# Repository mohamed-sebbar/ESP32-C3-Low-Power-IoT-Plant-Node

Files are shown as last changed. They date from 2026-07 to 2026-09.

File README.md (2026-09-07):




[]()
[]()

# ESP32-C3 Low-Power IoT Plant Node Rev 2.0

> Design and implementation of a compact low-power ESP32-C3 hardware platform for smart plant monitoring, environmental sensing and automated irrigation.

---

<p align="center">
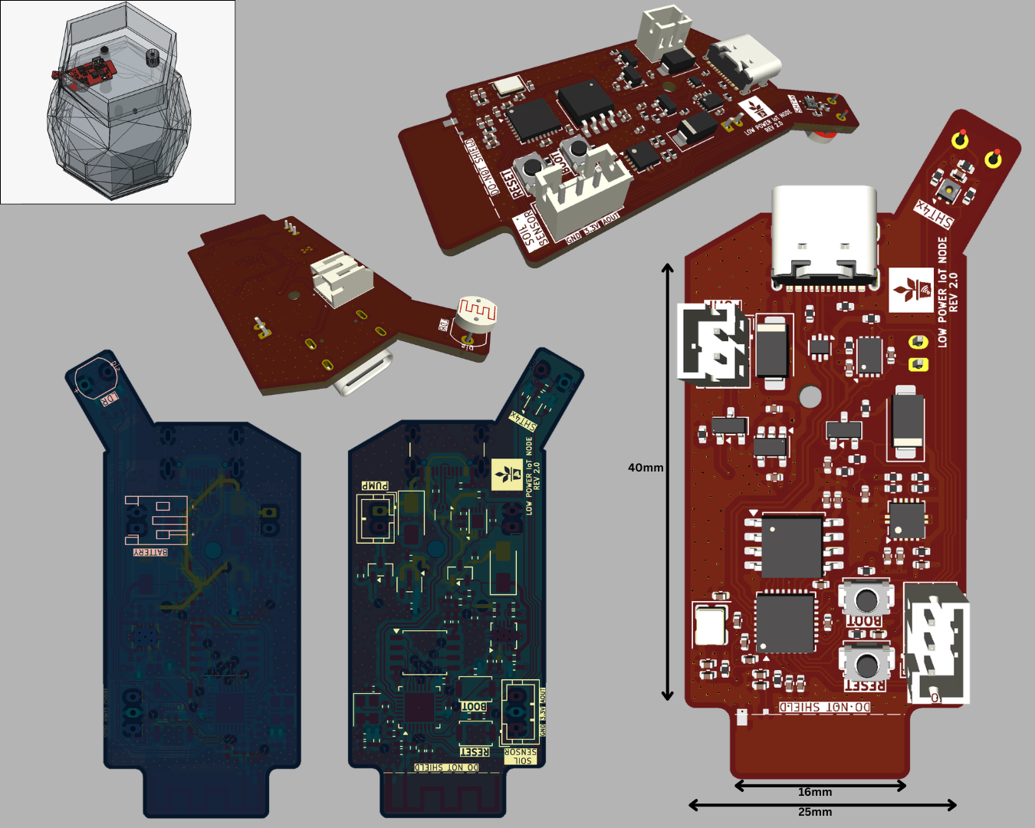
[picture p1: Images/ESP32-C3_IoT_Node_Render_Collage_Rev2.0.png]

</p>

---

## Overview

This repository presents the complete hardware design of a compact ESP32-C3 based IoT plant monitoring node developed as an engineering-focused redesign of a previously demonstrated smart irrigation concept.

Where the original project validated the overall application concept, this work focuses on the complete hardware architecture, RF-aware PCB layout, mixed-signal design, manufacturability, power integrity, and long-term maintainability of a production-oriented embedded platform.

The platform integrates environmental sensing, wireless communication, battery-ready power management and irrigation control within a compact four-layer PCB specifically designed for constrained enclosure geometries.

The goal of this repository is to document the engineering process behind the hardware rather than only presenting a finished PCB.

---

## Contents

- [Overview](#overview)
- [Key Features](#key-features)
- [Hardware Gallery](#hardware-gallery)
- [Repository Structure](#repository-structure)
- [Hardware Architecture](#hardware-architecture)
- [PCB Design Highlights](#pcb-design-highlights)
- [RF Design](#rf-design)
- [Manufacturing](#manufacturing)
- [Documentation](#documentation)
- [Future Work](#future-work)
- [Acknowledgements](#acknowledgements)
- [License](#license)
- [Author](#author)
- [Contact](#contact)

---

## Key Features

- Custom 4-layer PCB
- ESP32-C3 Wi-Fi MCU
- External SPI Flash
- USB-C Programming & Power
- Battery-ready architecture
- Battery charging circuitry
- Reverse polarity protection
- SHT40 Temperature & Humidity Sensor
- Capacitive Soil Moisture Interface
- MOSFET-controlled irrigation pump
- 2.4 GHz PCB antenna based on TI reference design
- RF-aware PCB layout
- Mixed-signal architecture
- Ground stitching
- Manufacturing-ready design

---

## Hardware Gallery

<p align="center">
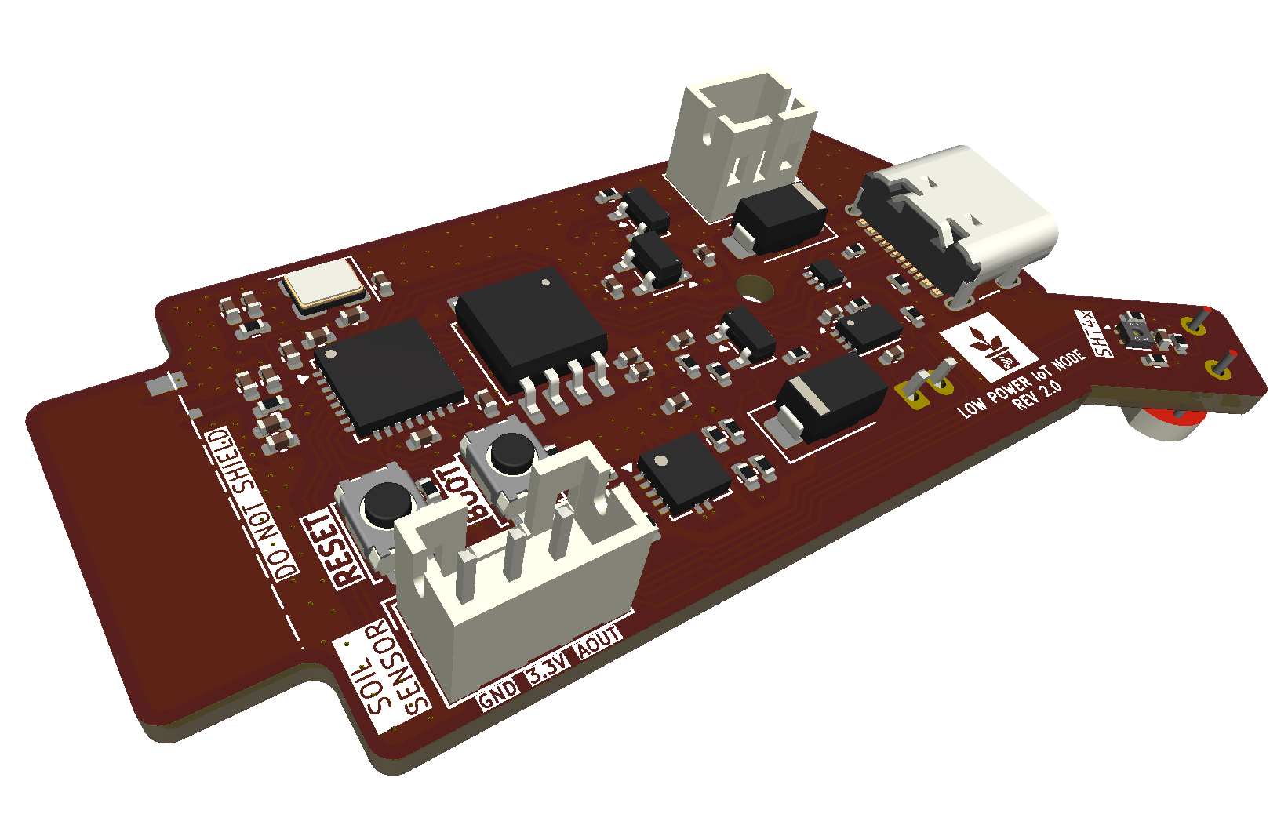
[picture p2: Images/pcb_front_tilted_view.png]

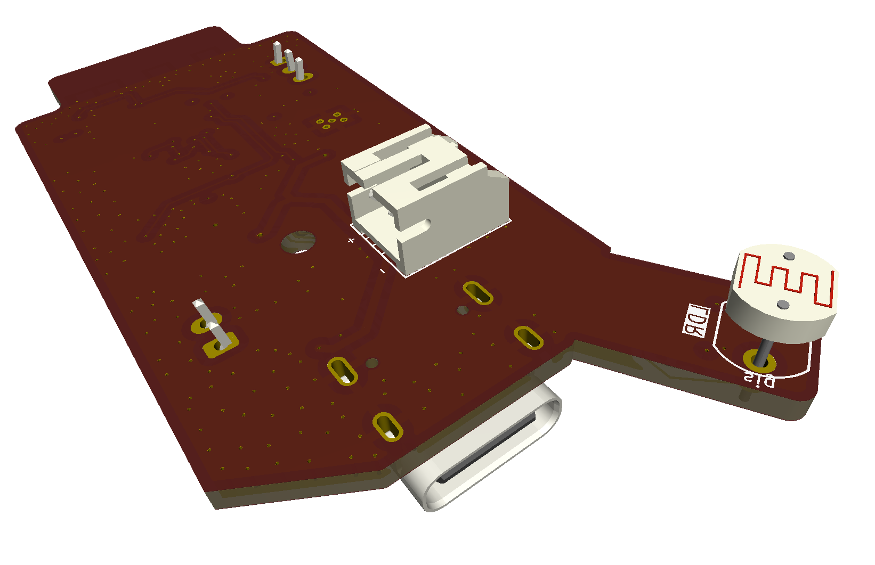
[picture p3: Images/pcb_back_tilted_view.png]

</p>

<p align="center">
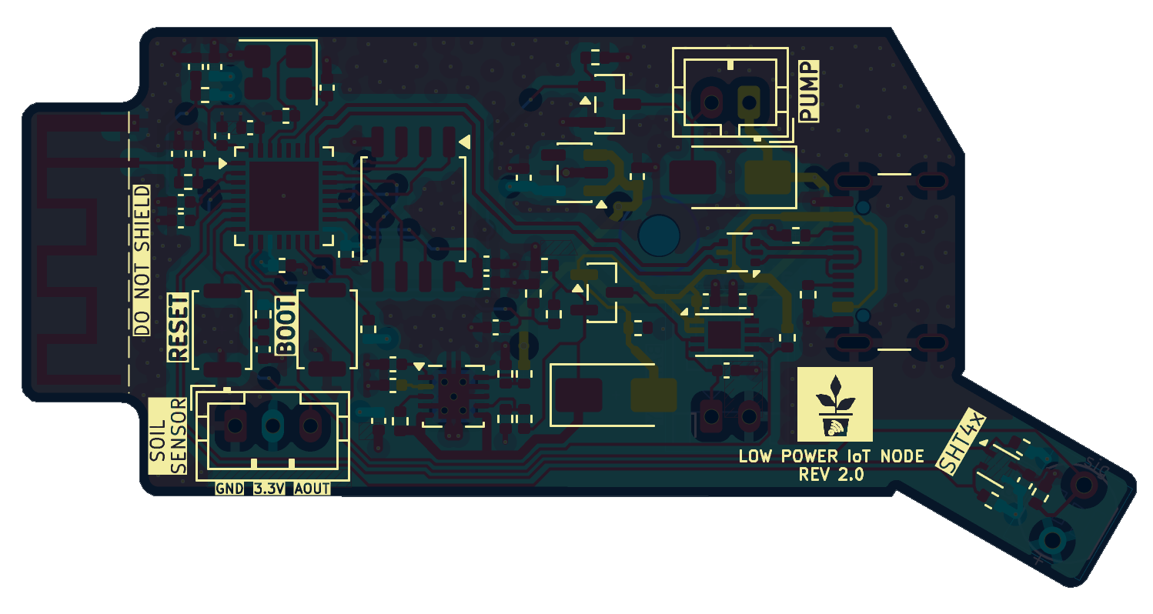
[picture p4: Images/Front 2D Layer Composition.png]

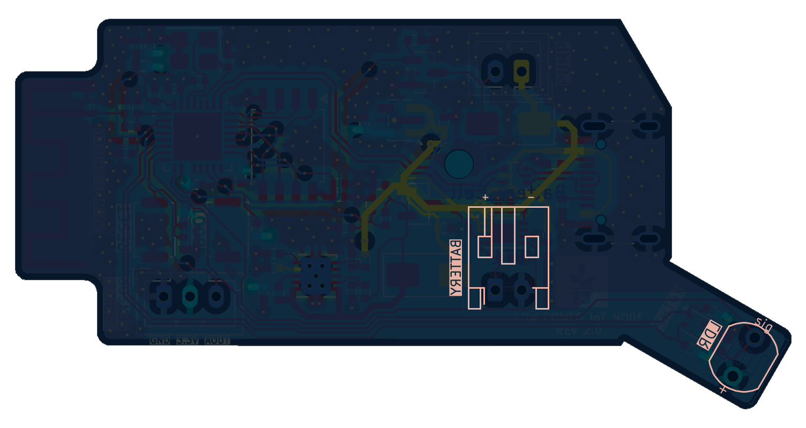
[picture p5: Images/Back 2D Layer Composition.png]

</p>

---

## Repository Structure

```text
ESP32-C3-Low-Power-IoT-Plant-Node

├── Hardware/
│   ├── KiCad Project
│   ├── Production
│   └── Libraries
│
├── Docs/
│   ├── 01_Schematic.pdf
│   └── 02_PCB_Assembly.pdf
│
├── LTspice_Sim
│
├── Images/
│
├── Logos/
│
├── 3D Models/
│
├── LICENSE
└── README.md
```
### Quick Access

- 📁 [Hardware](Hardware/)
- 📁 [Docs](Docs/)
- 📁 [LTspice_Sim](LTspice_Sim/)
- 📁 [Images](Images/)
- 📁 [Logos](Logos/)
- 📁 [3D Models](3D%20Models/)

---

## Hardware Architecture

The platform combines multiple engineering domains within a compact embedded hardware design.

**Processing**

- ESP32-C3
- External SPI Flash

**Environmental Sensing**

- SHT40 Temperature & Humidity
- Capacitive Soil Moisture Sensor

**Irrigation**

- MOSFET Pump Driver
- External Pump Connector

**Connectivity**

- Wi-Fi
- USB-C

**Power**

- USB & Battery powered
- Battery charging supported
- Reverse polarity protection
- Battery voltage monitoring

---

## PCB Design Highlights

The PCB was designed from the ground up with emphasis on engineering practices commonly employed in professional embedded hardware development.

Highlights include

- Four-layer stack-up
- Continuous ground reference planes
- Controlled RF keep-out
- Ground stitching vias
- Short crystal routing
- Careful decoupling placement
- USB differential routing
- Mixed analog/digital partitioning
- Compact constrained mechanical form factor

---

## RF Design

The wireless subsystem employs a PCB antenna derived from Texas Instruments reference **AN043** recommendations.

The antenna region includes

- dedicated RF keep-out
- controlled ground clearance
- dedicated feed routing
- configurable matching network

The initial values of the antenna matching network (L2, C21, C22) were selected based on theoretical calculations and RF design recommendations. Although these values are expected to operate correctly, final impedance matching should be verified after fabrication. For this reason, it is recommended to initially designate L2, C21, and C22 as DNP (Do Not Populate) and populate them only after RF characterization and tuning of the assembled hardware.

Detailed RF design notes will be provided in future documentation.

---

## Manufacturing

The repository includes fabrication outputs required for PCB production.

Included

- Gerber files
- Drill files
- Fabrication outputs

A generic Bill of Materials (BOM) is provided for design reference. Manufacturer-specific part numbers and sourcing information are intentionally omitted, allowing designers the flexibility to select equivalent components based on availability, cost, or project-specific requirements.

---

## Documentation

The repository documentation is being expanded and currently includes

- Schematic
- PCB Assembly
- LTspice power rail stability and transient response plots

Planned additions

- PCB Design Report
- RF Design Notes
- Signal and Power Integrity Discussion
- Design Validation

---

## Future Work

- Firmware adaptation
- Antenna impedance tuning
- Battery validation [Done]
- Power consumption characterization [Done]
- Environmental testing
- Long-term field deployment
- Companion mobile application integration

---

## Acknowledgements

The 3D planter model used in the project renders was created by **Lewis**. Full credit goes to the original author. The original model is available on the **Thingiverse** [Profile](https://www.thingiverse.com/thing:3537287).

The plant icon used on the PCB silkscreen is **"Smart Plant"** by **Anton Handal Saputra**, sourced from the **Noun Project**, and is used under the **Creative Commons Attribution 3.0 (CC BY 3.0)** license: https://thenounproject.com/browse/icons/term/smart-plant/

---

## License

The hardware design files are released under the CERN Open Hardware Licence Version 2 – Permissive (CERN-OHL-P). The accompanying files and written documentation remain © 2026 SEBBAR Mohamed and are provided for reference purposes only.

See [LICENSE](LICENSE) for details.

---

## Author

**Mohamed Sebbar**

Master's Degree in Computer Engineering and Embedded Systems

Faculty of Sciences, Agadir, Morocco

---

## Contact

If you have questions about this project, or would like to discuss the design feel free to:

- Open an [Issue](../../issues).
- Connect with me on [LinkedIn](https://www.linkedin.com/in/mohamedsebbar/).
- Or contact me via [email](mailto:sebbar.mohamed66@gmail.com).

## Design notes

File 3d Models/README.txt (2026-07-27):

Automatic Smart Plant Pot - (DIY, 3D Printed, Arduino, Self Watering, Project) by DIY_Machines on Thingiverse: https://www.thingiverse.com/thing:3537287

Summary:
Sometimes when we go away from home for a few days or are really busy the house plants (unfairly) suffer because they are not watered when they need it. This is my solution.All the electronics, pumps and water reservoir are contained inside the pot to keep it looking smart. Each pot (if you make more than one) can also be set to the needs of different types of plants.It has an Arduino Nano controlling everything and the cost of the components has been kept as low as possible. Below are links to the parts on Amazon.How to build it video: https://youtu.be/T_tpKoNCVYwCORRECTION: 4:05 into the video I incorrectly say to use 20cm wires to connect the water level sensor. The correct length is 35cm.==========List of items used in this project and where to find them (the links are Amazon affiliate links and help support this channel at no cost to you):■ Arduino Nano: https://geni.us/ArduinoNanoV3■ Mini submersible pump: https://geni.us/MiniPump■ 5mm tubing: https://geni.us/5mmTubing■ Transistor: https://geni.us/2npn2222■ Resistors (1k and 4.7k): https://geni.us/Ufa2s■ Wire: https://geni.us/22AWGWire■ 3mm LED: https://geni.us/LEDs■ Water level sensor: https://geni.us/WaterLevelSensor■ Nuts and Bolts: http://geni.us/NutsAndBolts■ Soil moisture sensor: https://geni.us/MoistureSensor■ Half Perma-proto board: https://geni.us/HalfPermaProto■ PLA Filament: https://geni.us/PLAFilament■ Battery powered glue gun: http://geni.us/BoschBatteryGlueGun■ Battery powered soldering iron:  http://bit.ly/SealeySDL6 ==========The code can be downloaded from here: https://github.com/DIY-Machines/SmartPlantV1==========SAY THANKS:Buy me a coffee to say thanks: https://ko-fi.com/diymachinesSupport me on Patreon: https://www.patreon.com/diymachinesSUBSCRIBE:■ https://www.youtube.com/channel/UC3jc4X-kEq-dEDYhQ8QoYnQ?sub_confirmation=1INSTAGRAM: https://www.instagram.com/diy_machines/?hl=enFACEBOOK: https://www.facebook.com/diymachines/Disclaimer:This video is shared for demonstration purposes only.

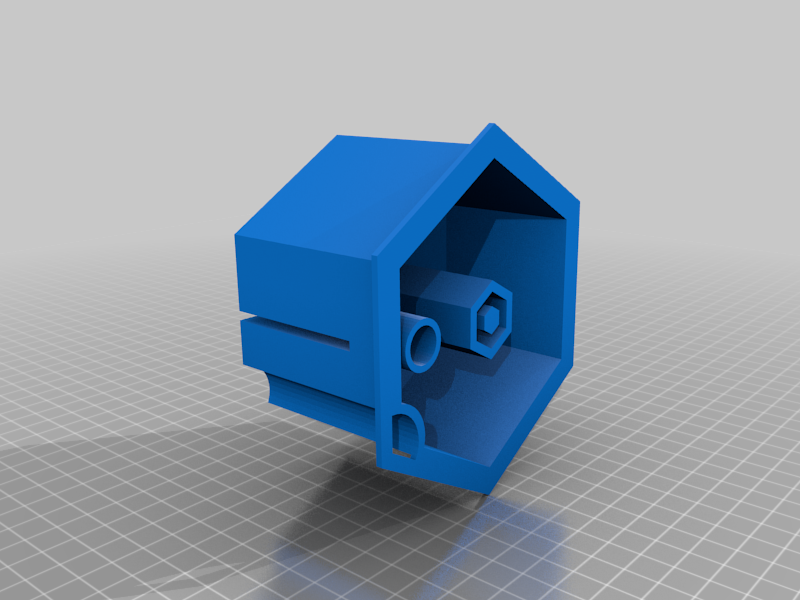
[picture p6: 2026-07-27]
3d Models/images/3d78d03c32c9cba0c1dec2c4151a06b8.png

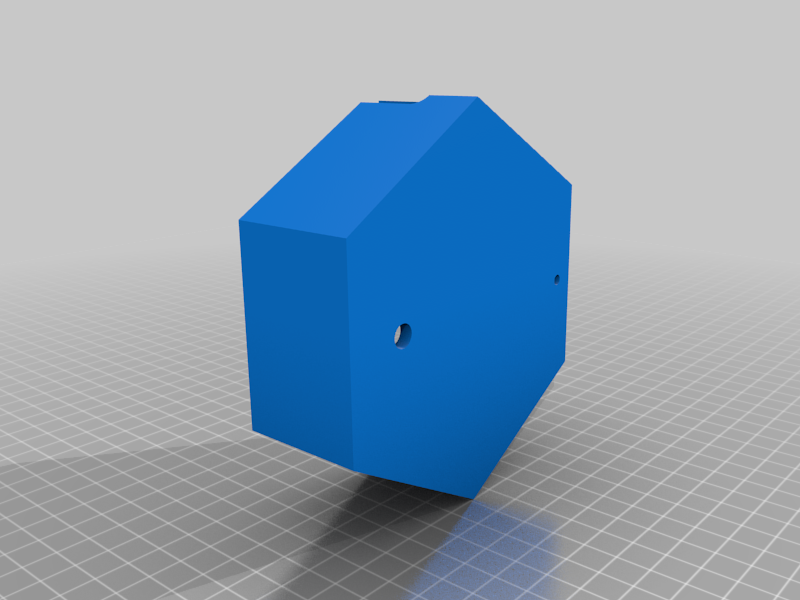
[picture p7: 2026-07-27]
3d Models/images/6778b36fcebb03efd6b67b2f8be7a825.png

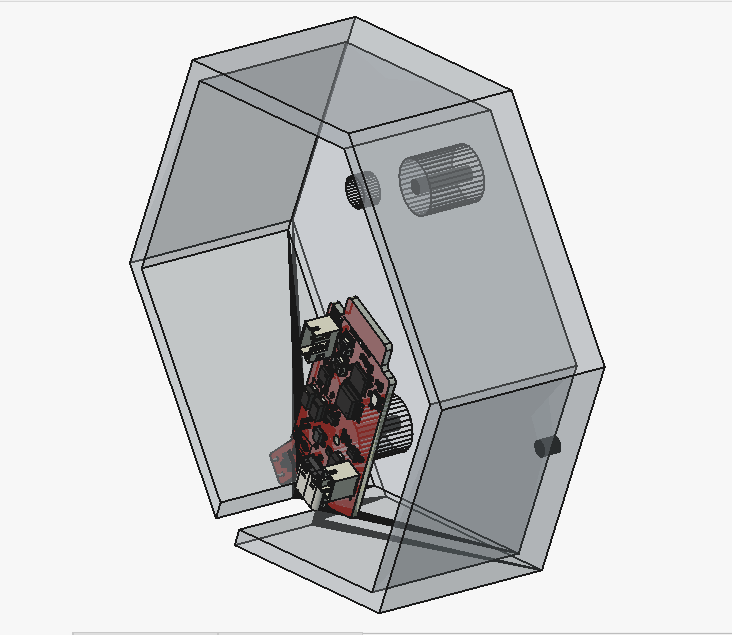
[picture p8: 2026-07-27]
Images/product_tilted_view_2.png

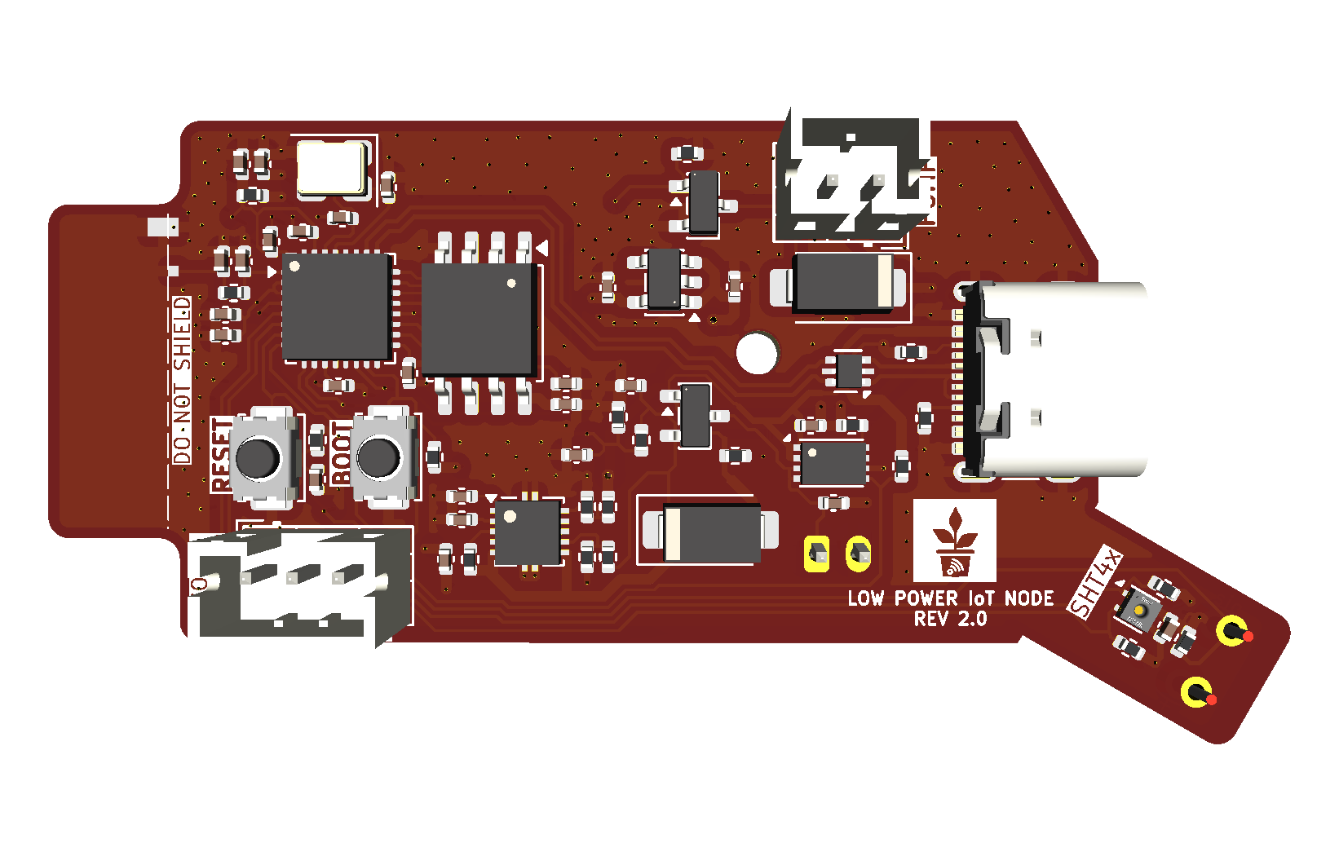
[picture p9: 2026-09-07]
Images/pcb_front.png

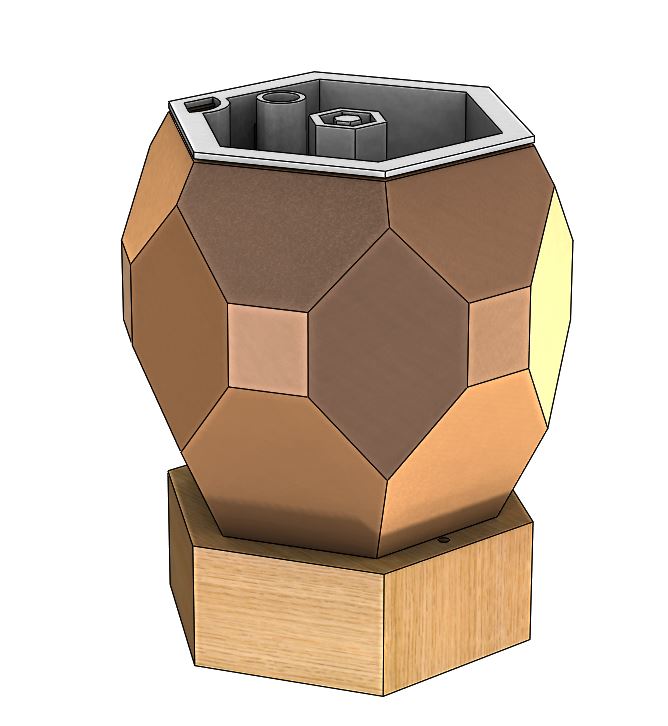
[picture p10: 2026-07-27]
3d Models/images/Solidworks_Model_Photo.JPG

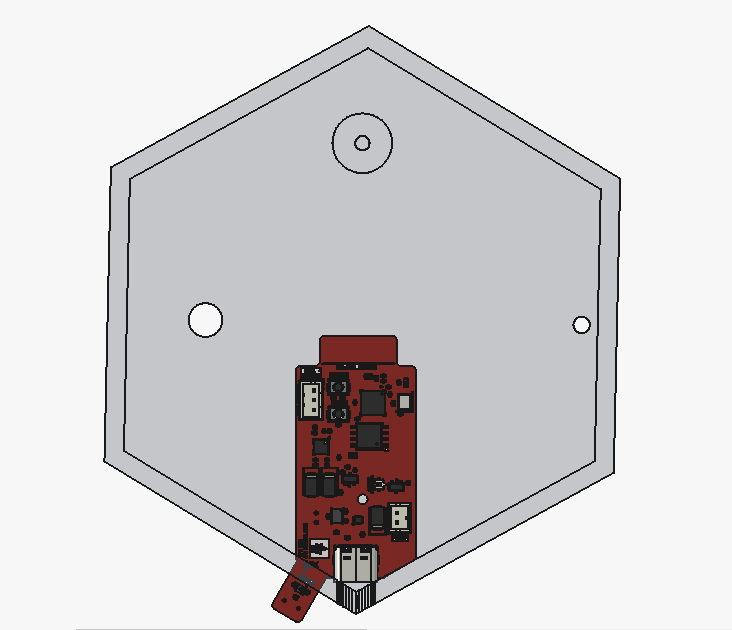
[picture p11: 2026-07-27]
Images/product_rear_view.png

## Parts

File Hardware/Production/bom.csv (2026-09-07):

Designator | Footprint | Quantity | Value | LCSC Part #
ANT1 | RF_TI_Antena_2.4GHz_flipped | 1 | ~
BT1 | JST_PH_S2B-PH-K_1x02_P2.00mm_Horizontal | 1 | Battery_Cell
C1, C14 | 0402 | 2 | 10uF
C10, C13, C19, C2, C20, C3, C4, C5, C6, C7 | 0402 | 10 | 100nF
C11, C12 | 0402 | 2 | 10pF
C15, C16, C17 | 0402 | 3 | 4.7uF
C18, C23, C24, C25, C8, C9 | 0402 | 6 | 1uF
C21, C22 | 0402 | 2 | 3.3pF
D1, D3 | D_SMA | 2 | SS14
FB1 | 0402 | 1 | 600R
J1 | USB_C_Receptacle_GCT_USB4105-xx-A_16P_TopMnt_Horizontal | 1 | USB_C_Receptacle_USB2.0_16P
J2 | JST_PH_B2B-PH-K_1x02_P2.00mm_Vertical | 1 | Pump
J3 | JST_PH_B3B-PH-K_1x03_P2.00mm_Vertical | 1 | Soil Sensor
L1 | 0402 | 1 | 2.2uH
L2 | 0402 | 1 | 2.2nH
LDR1 | R_LDR_5.1x4.3mm_P3.4mm_Vertical | 1 | LDR07
Q1 | SOT-23 | 1 | Q_PMOS_GSD
Q2 | SOT-23 | 1 | Q_NMOS_GSD
R1, R2 | 0402 | 2 | 5.1K
R10, R8 | 0402 | 2 | 910K
R11 | 0402 | 1 | 100K
R12 | 0402 | 1 | 562K
R13, R9 | 0402 | 2 | 180K
R14, R17, R3, R4, R5, R6, R7 | 0402 | 7 | 10K
R15, R16 | 0402 | 2 | 4.7K
SW1, SW2 | SW_Push_SPST_NO_Alps_SKRK | 2 | SW_Push
U1 | QFN-32-1EP_5x5mm_P0.5mm_EP3.7x3.7mm | 1 | ESP32-C3
U2 | SOT-666 | 1 | USBLC6-2P6
U3 | Sensirion_DFN-4_1.5x1.5mm_P0.8mm_SHT4x_NoCentralPad | 1 | SHT4x
U4 | SOIC-8_5.3x5.3mm_P1.27mm | 1 | W25Q16JVSS
U5 | Texas_S-PVSON-N10_ThermalVias | 1 | TPS61200DRC
U6 | DFN-8-1EP_3x2mm_P0.5mm_EP1.75x1.45mm | 1 | MCP73831-2-MC
U8 | SOT-23-5 | 1 | TLV75733PDBV
Y1 | Crystal_SMD_3225-4Pin_3.2x2.5mm | 1 | 40MHz

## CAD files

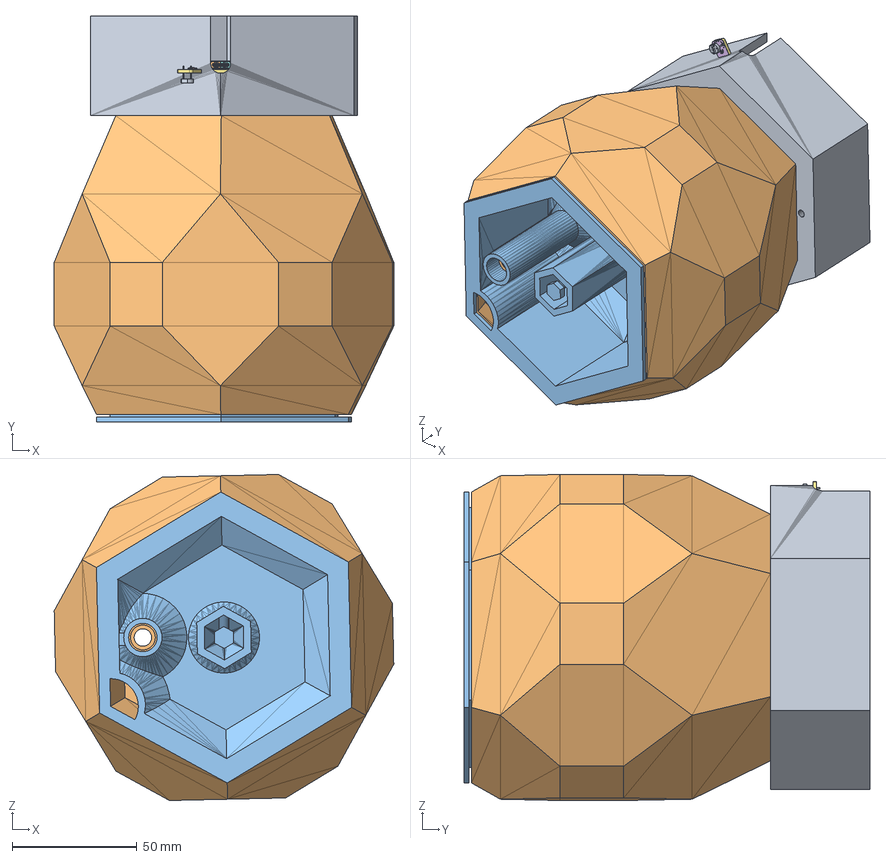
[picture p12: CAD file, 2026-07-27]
3d Models/files/full_pcb_pot.FCStd
136.3 x 163.0 x 130.9 mm
Stand002
Outer_Pot002
Inner_Pot002
C_0402_1005Metric
C_0402_1005Metric002
C_0402_1005Metric004
R_0402_1005Metric
R_0402_1005Metric002
C_0402_1005Metric006
QFN-32-1EP_5x5mm_P0.5mm_EP3.7x3.7mm
JST_B3B_PH_K
C_0402_1005Metric008
Texas_S_PVSON_N10
R_0402_1005Metric004
C_0402_1005Metric010
D_SMA
SW_Push_SPST_NO_Alps_SKRK
C_0402_1005Metric012
SOIC-8_5.3x5.3mm_P1.27mm
C_0402_1005Metric014
R_0402_1005Metric006
C_0402_1005Metric016
C_0402_1005Metric018
SOT_666
C_0402_1005Metric020
C_0402_1005Metric022
MCP73831-2ACI_MC
MCP73831-2ACI_MC001
MCP73831-2ACI_MC002
MCP73831-2ACI_MC003
MCP73831-2ACI_MC004
MCP73831-2ACI_MC005
MCP73831-2ACI_MC006
MCP73831-2ACI_MC007
MCP73831-2ACI_MC008
MCP73831-2ACI_MC009
MCP73831-2ACI_MC010
SOT-23
Crystal_SMD_3225-4Pin_3.2x2.5mm
USB_C_Receptacle_16P_TopMnt_Horizontal_GCT_USB4105-xx-A
USB_C_Receptacle_16P_TopMnt_Horizontal_GCT_USB4105-xx-A001
USB_C_Receptacle_16P_TopMnt_Horizontal_GCT_USB4105-xx-A002
USB_C_Receptacle_16P_TopMnt_Horizontal_GCT_USB4105-xx-A003
USB_C_Receptacle_16P_TopMnt_Horizontal_GCT_USB4105-xx-A004
USB_C_Receptacle_16P_TopMnt_Horizontal_GCT_USB4105-xx-A005
USB_C_Receptacle_16P_TopMnt_Horizontal_GCT_USB4105-xx-A006
USB_C_Receptacle_16P_TopMnt_Horizontal_GCT_USB4105-xx-A007
USB_C_Receptacle_16P_TopMnt_Horizontal_GCT_USB4105-xx-A008
USB_C_Receptacle_16P_TopMnt_Horizontal_GCT_USB4105-xx-A009
USB_C_Receptacle_16P_TopMnt_Horizontal_GCT_USB4105-xx-A010
USB_C_Receptacle_16P_TopMnt_Horizontal_GCT_USB4105-xx-A011
USB_C_Receptacle_16P_TopMnt_Horizontal_GCT_USB4105-xx-A012
USB_C_Receptacle_16P_TopMnt_Horizontal_GCT_USB4105-xx-A013
USB_C_Receptacle_16P_TopMnt_Horizontal_GCT_USB4105-xx-A014
USB_C_Receptacle_16P_TopMnt_Horizontal_GCT_USB4105-xx-A015
USB_C_Receptacle_16P_TopMnt_Horizontal_GCT_USB4105-xx-A016
USB_C_Receptacle_16P_TopMnt_Horizontal_GCT_USB4105-xx-A017
USB_C_Receptacle_16P_TopMnt_Horizontal_GCT_USB4105-xx-A018
USB_C_Receptacle_16P_TopMnt_Horizontal_GCT_USB4105-xx-A019
USB_C_Receptacle_16P_TopMnt_Horizontal_GCT_USB4105-xx-A020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

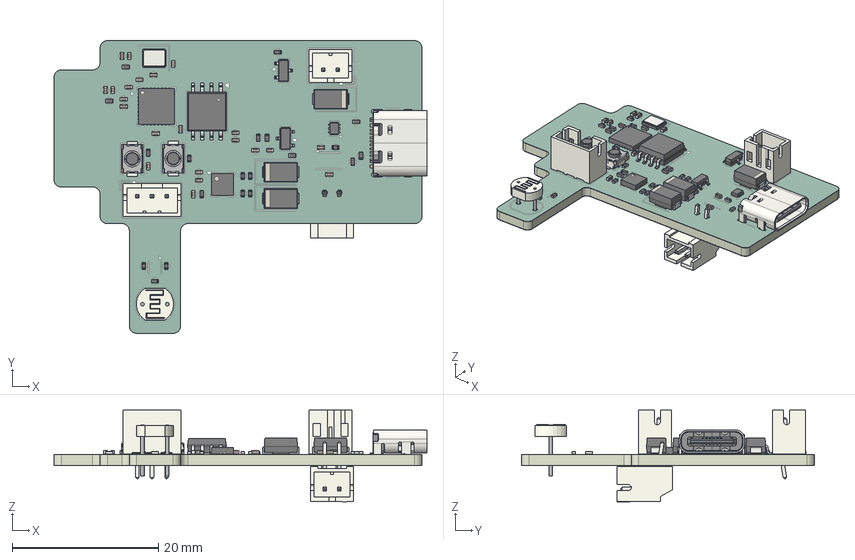
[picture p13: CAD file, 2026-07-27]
.step
51.0 x 40.0 x 12.5 mm
C_0402_1005Metric x 22
R_0402_1005Metric x 20
QFN-32-1EP_5x5mm_P0.5mm_EP3.7x3.7mm
JST_B3B_PH_K
Texas_S_PVSON_N10
D_SMA x 3
SW_Push_SPST_NO_Alps_SKRK x 2
SOIC-8_5.3x5.3mm_P1.27mm
SOT_666
SOT-23 x 2
Crystal_SMD_3225-4Pin_3.2x2.5mm
USB_C_Receptacle_16P_TopMnt_Horizontal_GCT_USB4105-xx-A
R_LDR_5.1x4.3mm_P3.4mm_Vertical
JST_B2B_PH_K
JST_S2B_PH_K
Low-Power_ESP32_Irrigation_Controller_silkscreen x 2
Low-Power_ESP32_Irrigation_Controller_soldermask x 2
Low-Power_ESP32_Irrigation_Controller_PCB

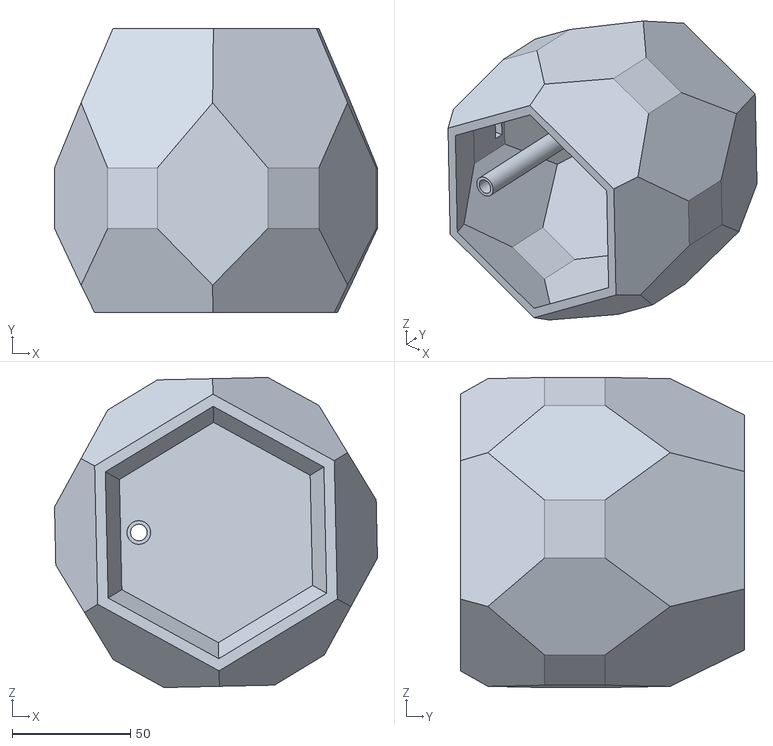
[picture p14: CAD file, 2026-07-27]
3d Models/files/Outer_Pot.STL
136.3 x 120.0 x 130.9

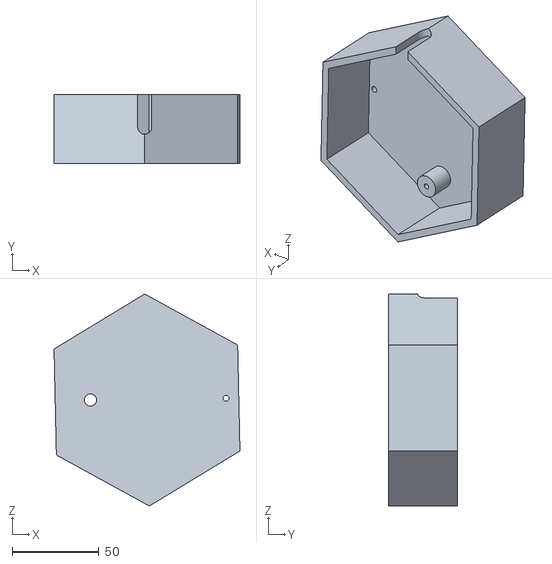
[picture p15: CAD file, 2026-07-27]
3d Models/files/Stand.STL
107.2 x 40.0 x 122.2

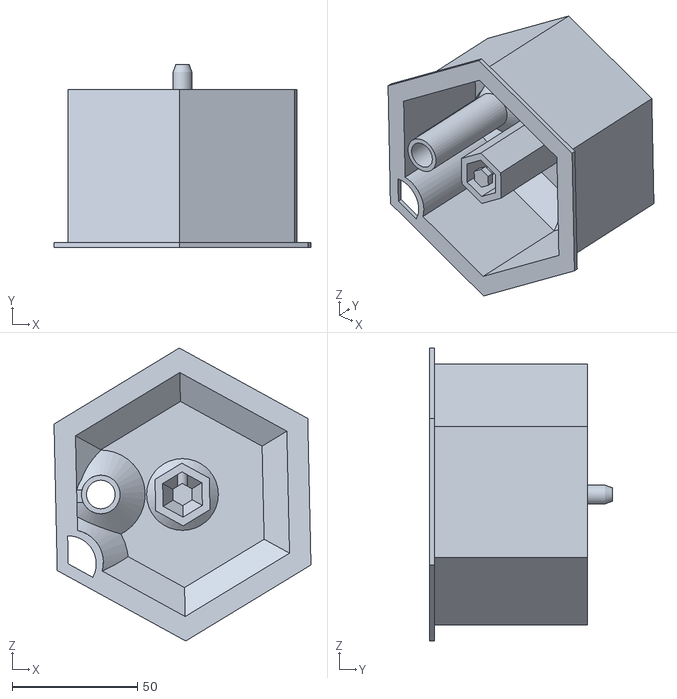
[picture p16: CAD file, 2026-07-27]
3d Models/files/Inner_Pot.STL
102.4 x 73.0 x 116.8

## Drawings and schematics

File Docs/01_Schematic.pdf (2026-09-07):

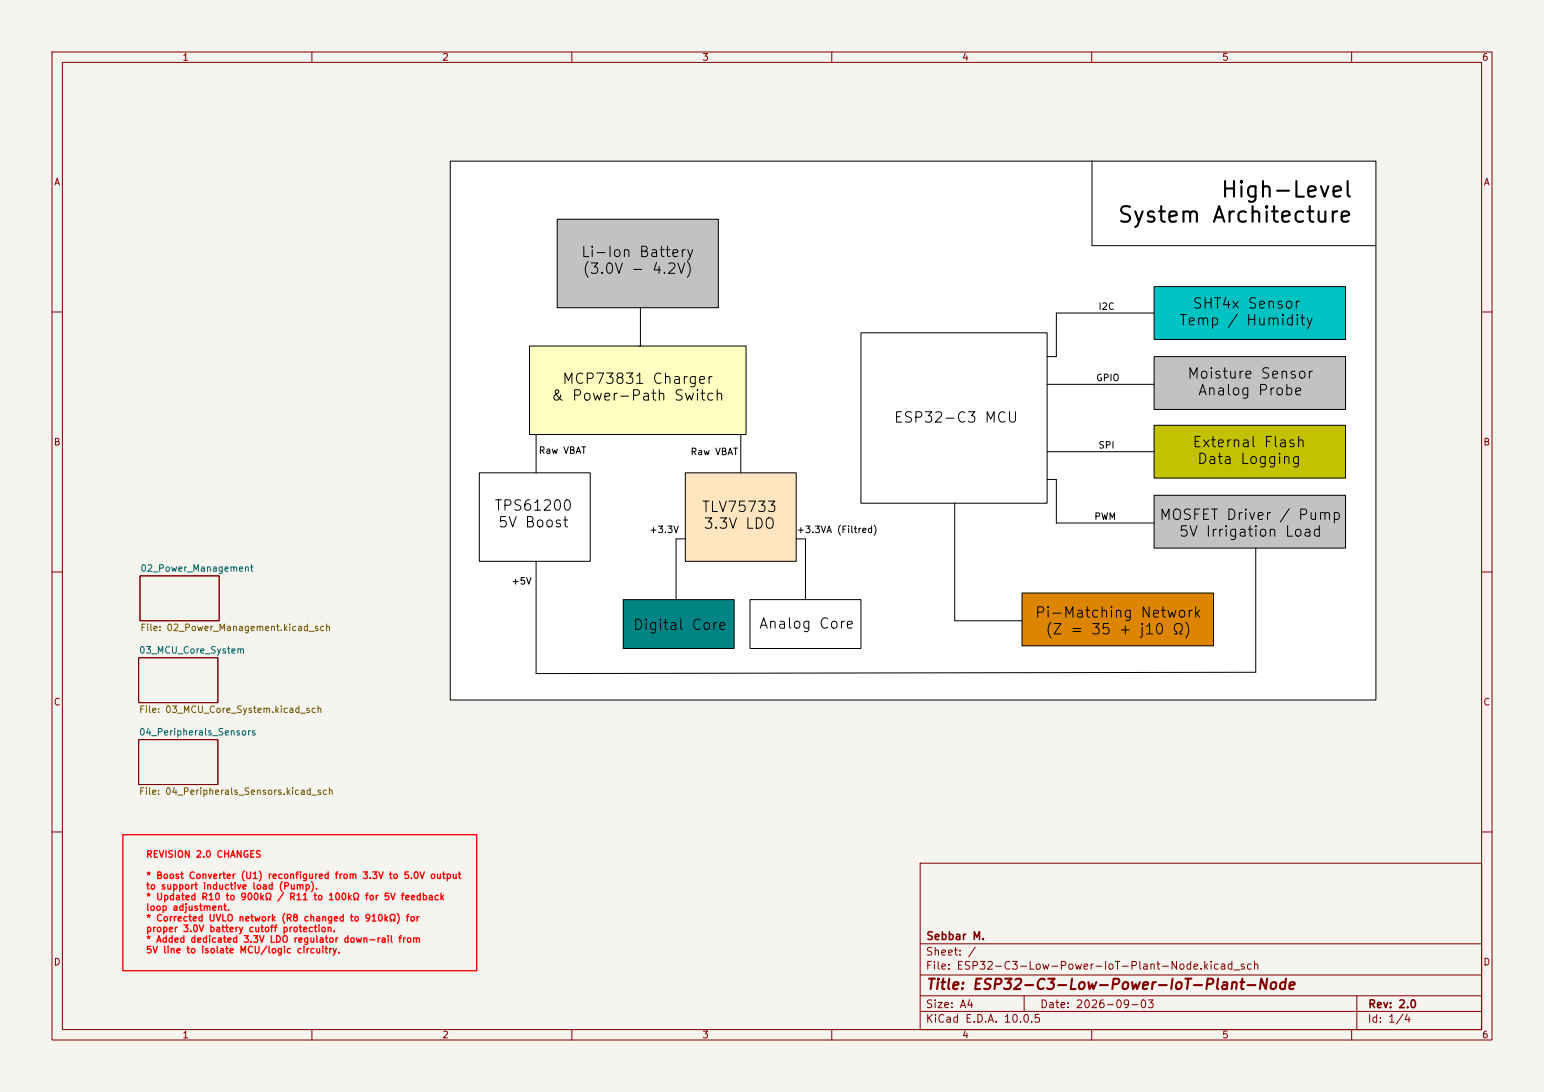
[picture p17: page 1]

SPI PWM Analog Core

* Boost Converter (U1) reconfigured from 3.3V to 5.0V output
to support inductive load (Pump). * Updated R10 to 900kΩ / R11 to 100kΩ for 5V feedback

loop adjustment. * Corrected UVLO network (R8 changed to 910kΩ) for proper 3.0V battery cutoff protection. * Added dedicated 3.3V LDO regulator down-rail from 5V line to isolate MCU/logic circuitry.

Sebbar M.
Sheet: /
File: ESP32-C3-Low-Power-IoT-Plant-Node.kicad_sch
Title: ESP32-C3-Low-Power-IoT-Plant-Node

Size: A4 | Rev: 2.0
KiCad E.D.A. 10.0.5 | Id: 1/4

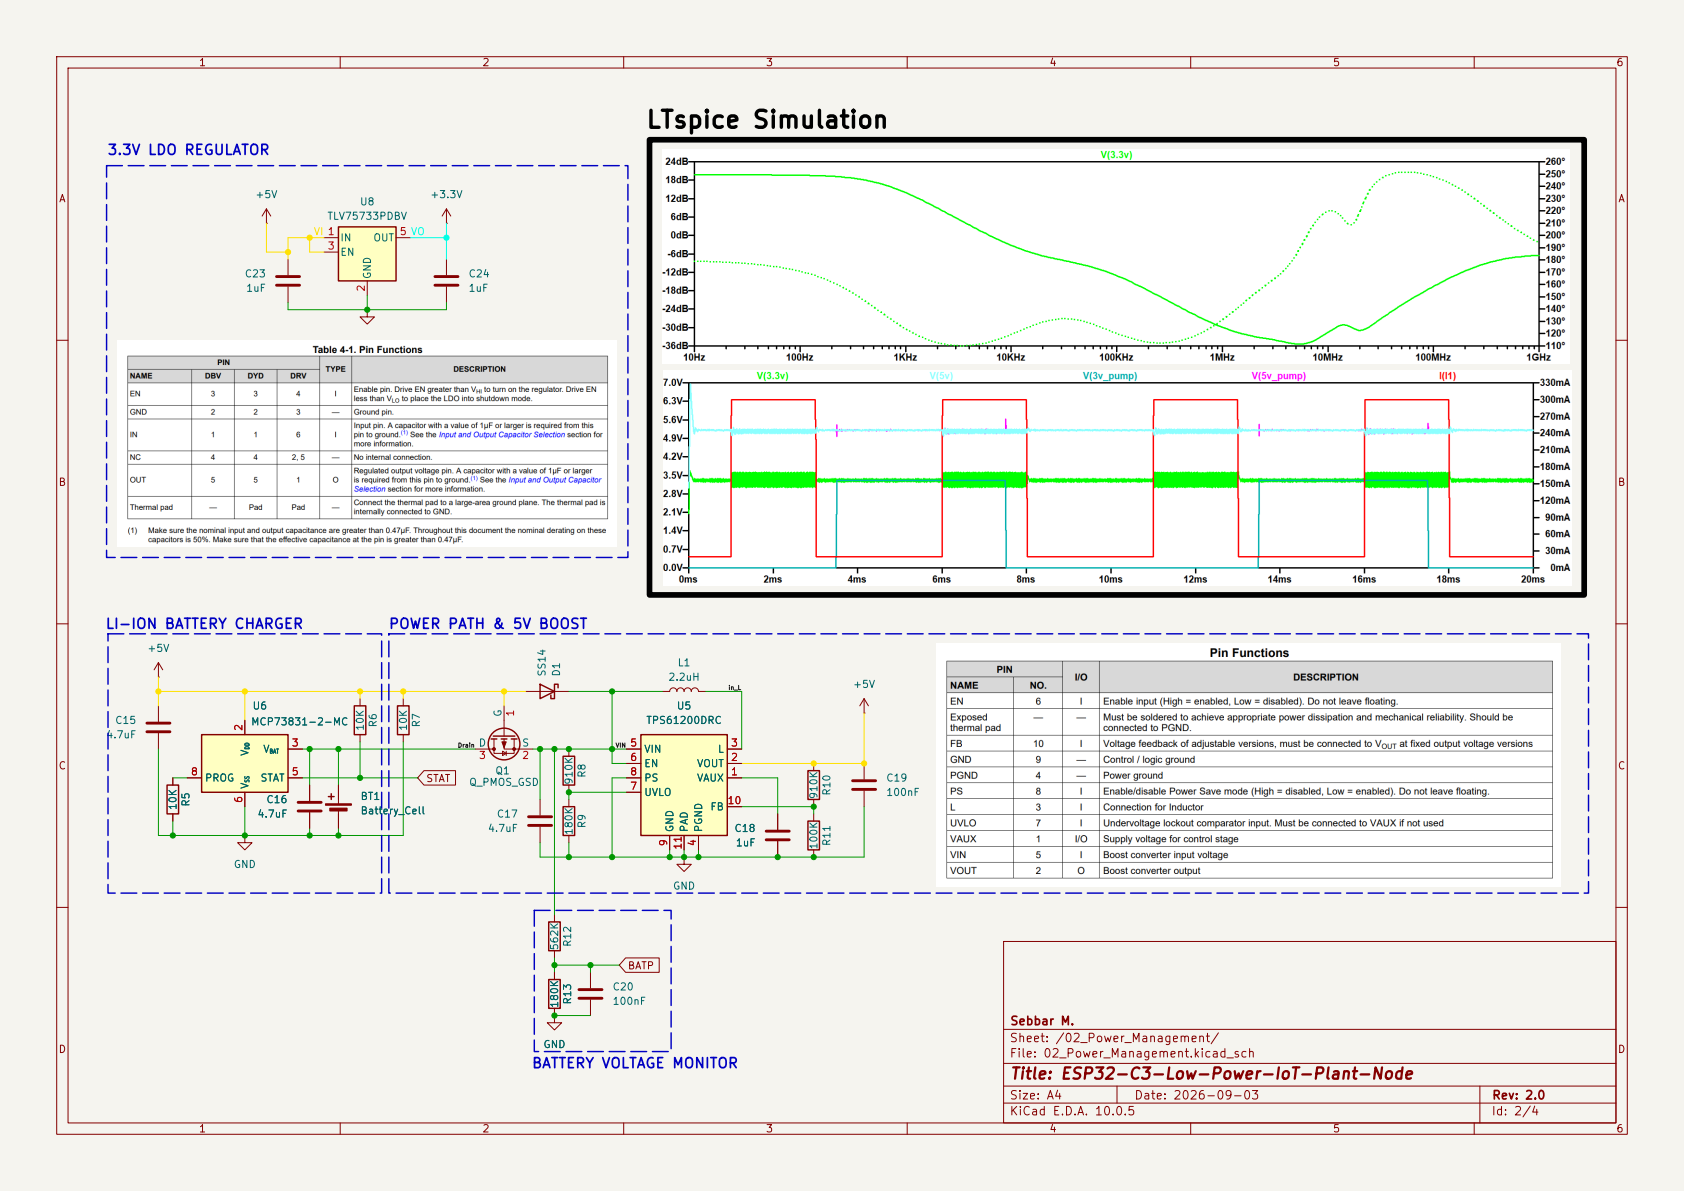
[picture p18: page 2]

LI-ION BATTERY CHARGER

Sheet: /02_Power_Management/
File: 02_Power_Management.kicad_sch
Title: ESP32-C3-Low-Power-IoT-Plant-Node

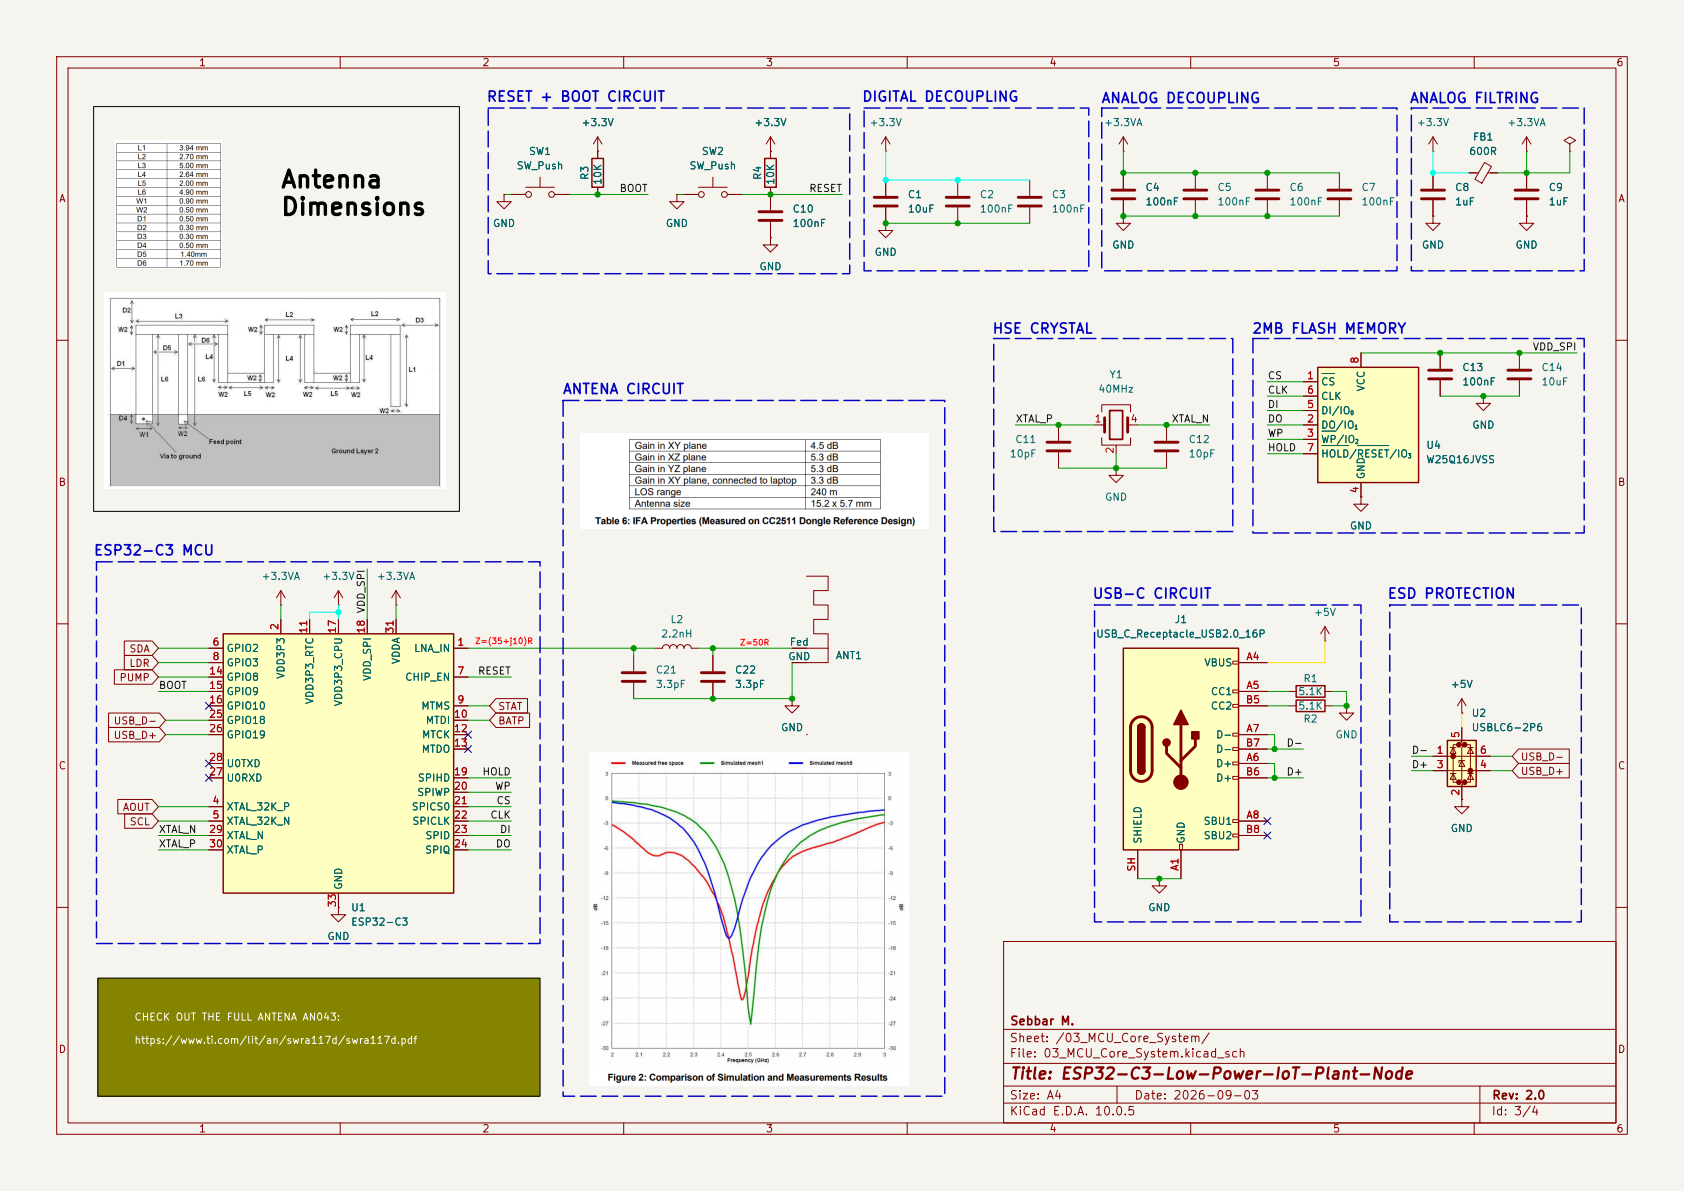
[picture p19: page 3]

4 DI/IO0 5 CLK 6 HOLD/RESET/IO3 7 VCC

CHECK OUT THE FULL ANTENA AN043: https://www.ti.com/lit/an/swra117d/swra117d.pdf

Sebbar M.
Sheet: /03_MCU_Core_System/
File: 03_MCU_Core_System.kicad_sch
Title: ESP32-C3-Low-Power-IoT-Plant-Node

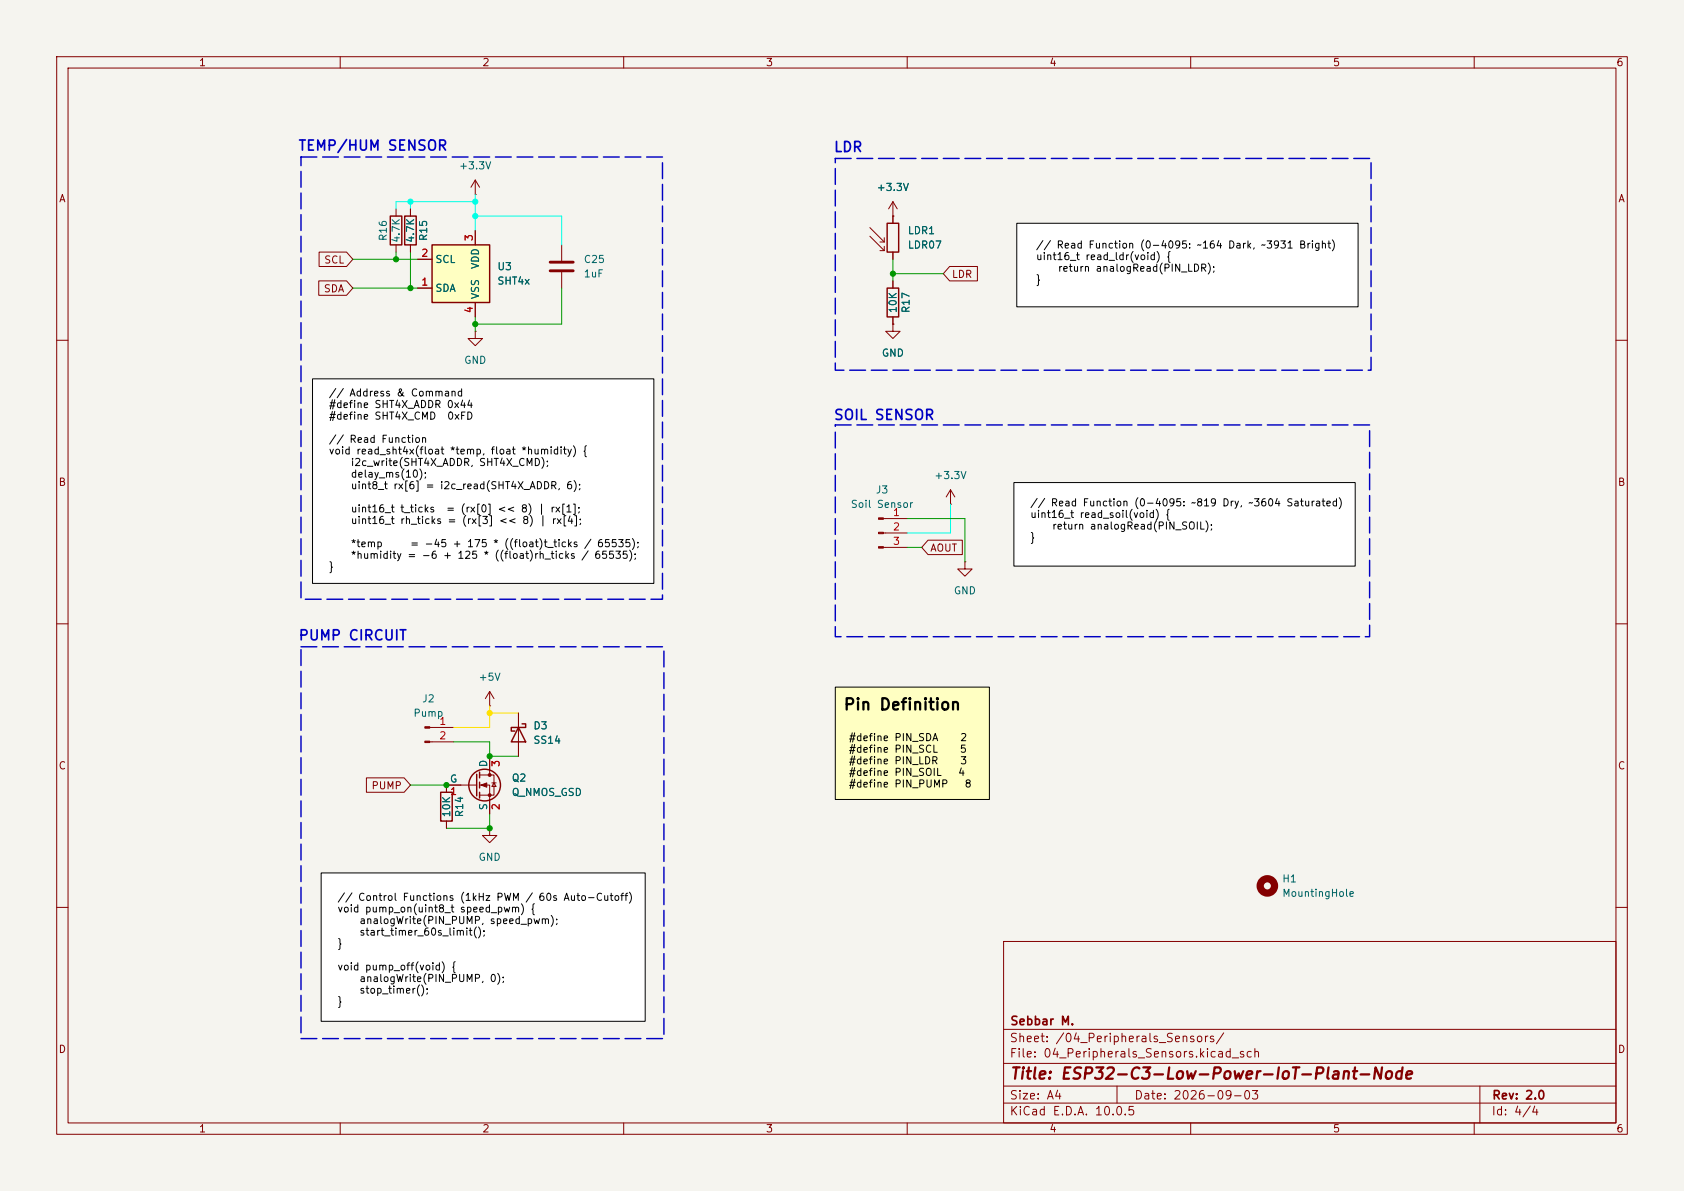
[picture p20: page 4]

// Read Function (0-4095: ~164 Dark, ~3931 Bright) uint16_t read_ldr(void) {

// Address & Command #define SHT4X_ADDR 0x44 #define SHT4X_CMD 0xFD // Read Function

void read_sht4x(float *temp, float *humidity) {
i2c_write(SHT4X_ADDR, SHT4X_CMD); delay_ms(10); uint8_t rx[6] = i2c_read(SHT4X_ADDR, 6); uint16_t t_ticks = (rx[0] << 8) | rx[1]; uint16_t rh_ticks = (rx[3] << 8) | rx[4];

// Read Function (0-4095: ~819 Dry, ~3604 Saturated) uint16_t read_soil(void) {

// Control Functions (1kHz PWM / 60s Auto-Cutoff) void pump_on(uint8_t speed_pwm) { analogWrite(PIN_PUMP, speed_pwm); start_timer_60s_limit(); }void pump_off(void) { analogWrite(PIN_PUMP, 0); stop_timer(); }

Sheet: /04_Peripherals_Sensors/
File: 04_Peripherals_Sensors.kicad_sch
Title: ESP32-C3-Low-Power-IoT-Plant-Node

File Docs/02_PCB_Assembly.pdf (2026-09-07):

# 40mm 25mm

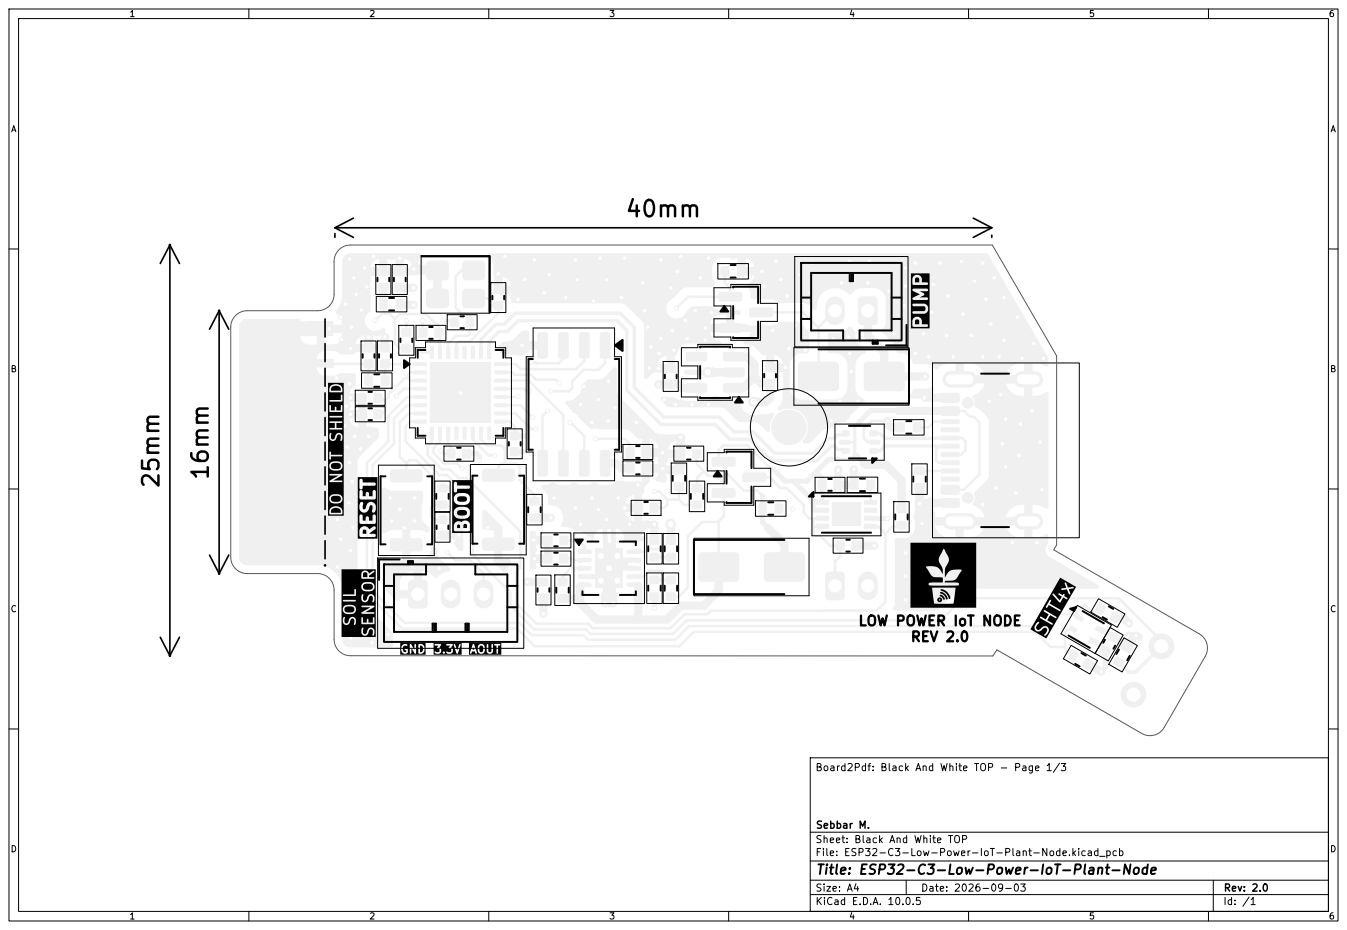
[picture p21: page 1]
D Date: 2026-09-03; Size: A4; Rev: 2.0

LOW POWER IoT NODE REV 2.0 16mm

Board2Pdf: Black And White TOP - Page 1/3

Sebbar M.
Sheet: Black And White TOP
File: ESP32-C3-Low-Power-IoT-Plant-Node.kicad_pcb
Title: ESP32-C3-Low-Power-IoT-Plant-Node
KiCad E.D.A. 10.0.5

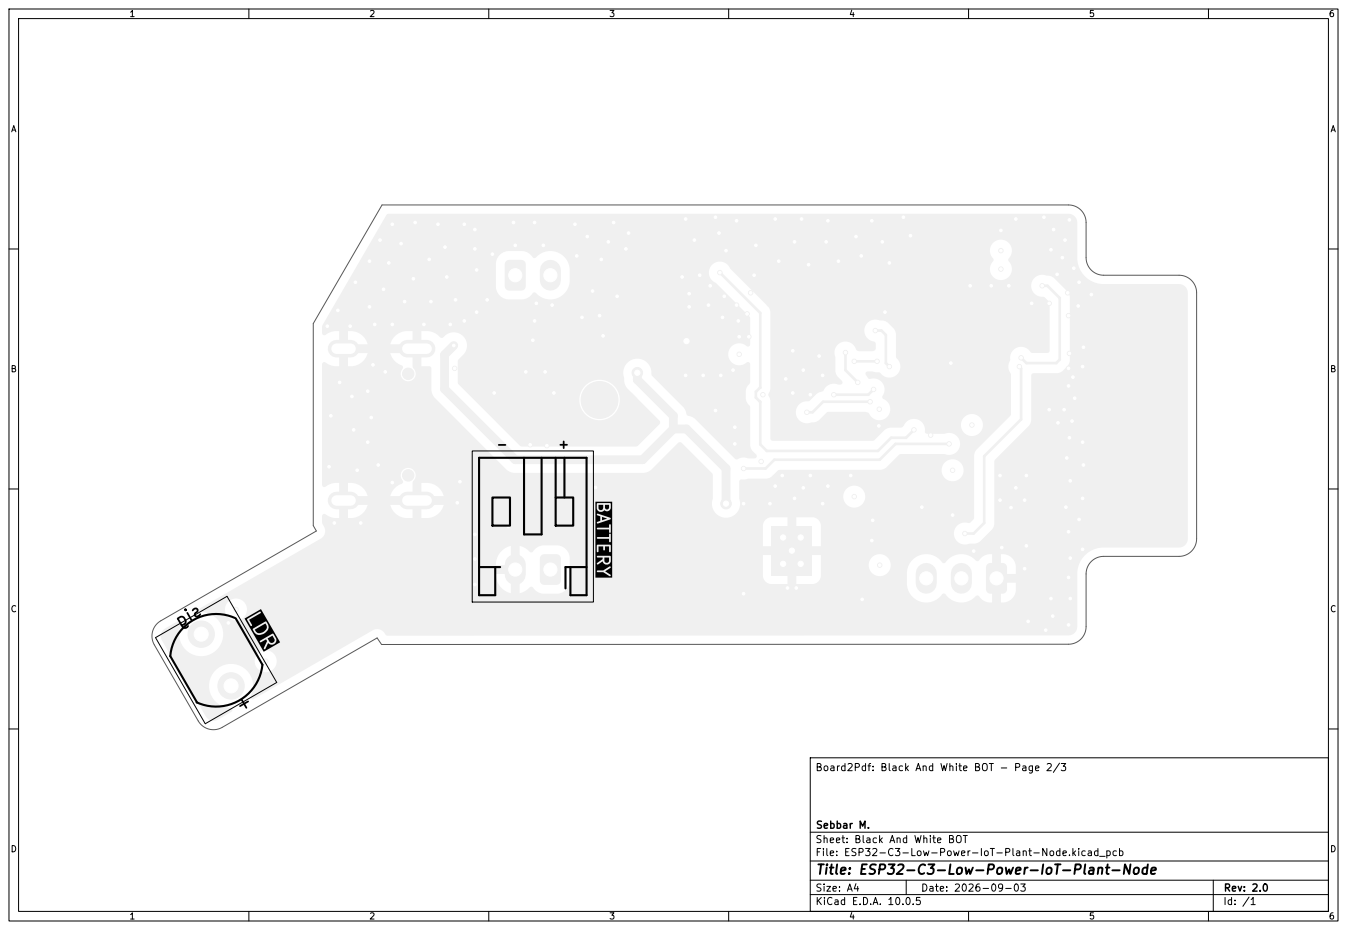
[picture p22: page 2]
D Date: 2026-09-03

Board2Pdf: Black And White BOT - Page 2/3

Sebbar M.
Sheet: Black And White BOT
File: ESP32-C3-Low-Power-IoT-Plant-Node.kicad_pcb
Title: ESP32-C3-Low-Power-IoT-Plant-Node

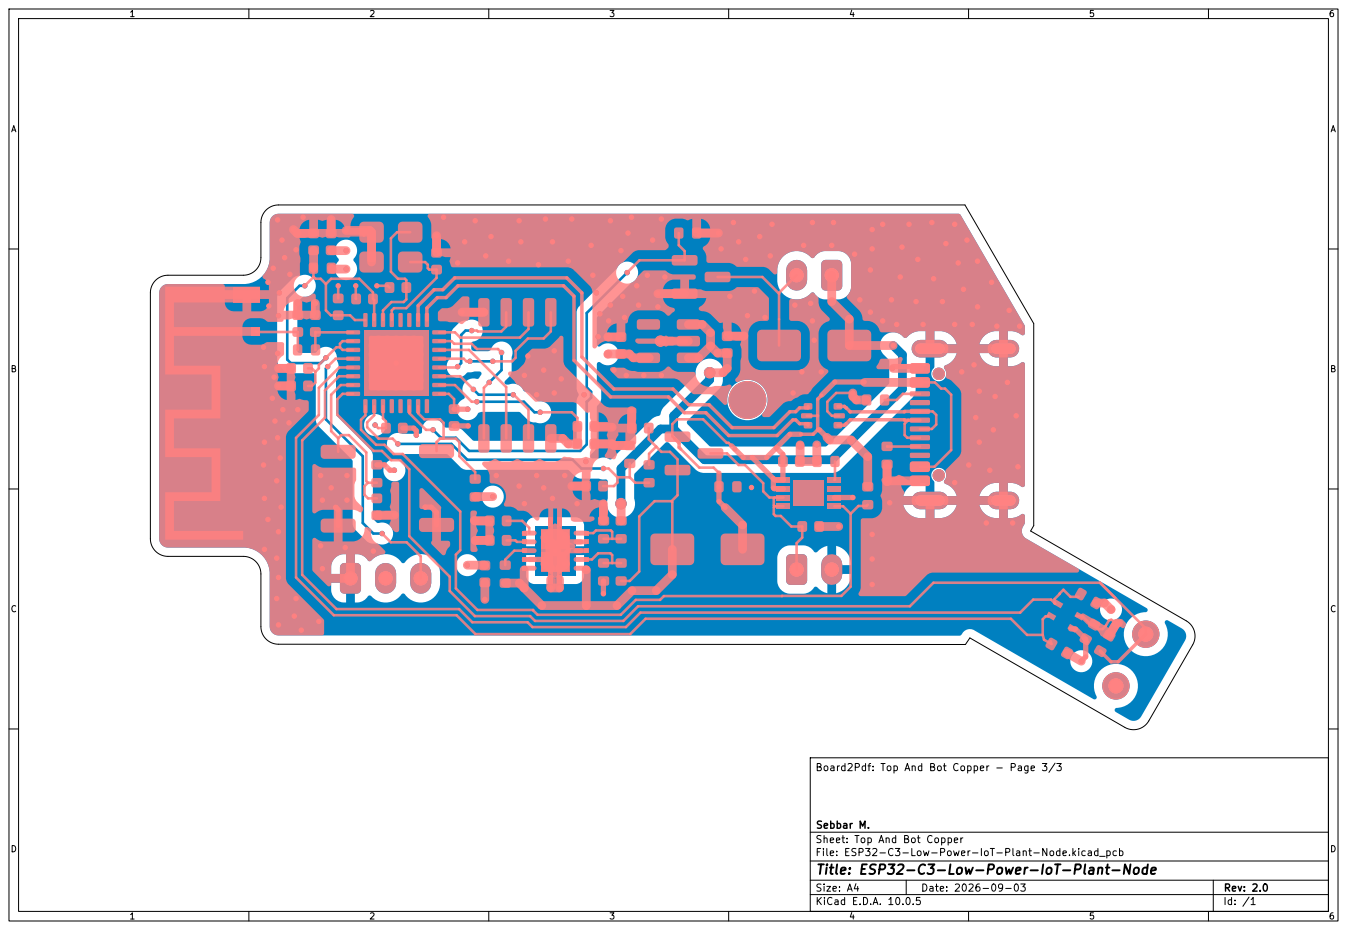
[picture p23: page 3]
D Date: 2026-09-03

Board2Pdf: Top And Bot Copper - Page 3/3

Sebbar M.
Sheet: Top And Bot Copper
File: ESP32-C3-Low-Power-IoT-Plant-Node.kicad_pcb
Title: ESP32-C3-Low-Power-IoT-Plant-Node

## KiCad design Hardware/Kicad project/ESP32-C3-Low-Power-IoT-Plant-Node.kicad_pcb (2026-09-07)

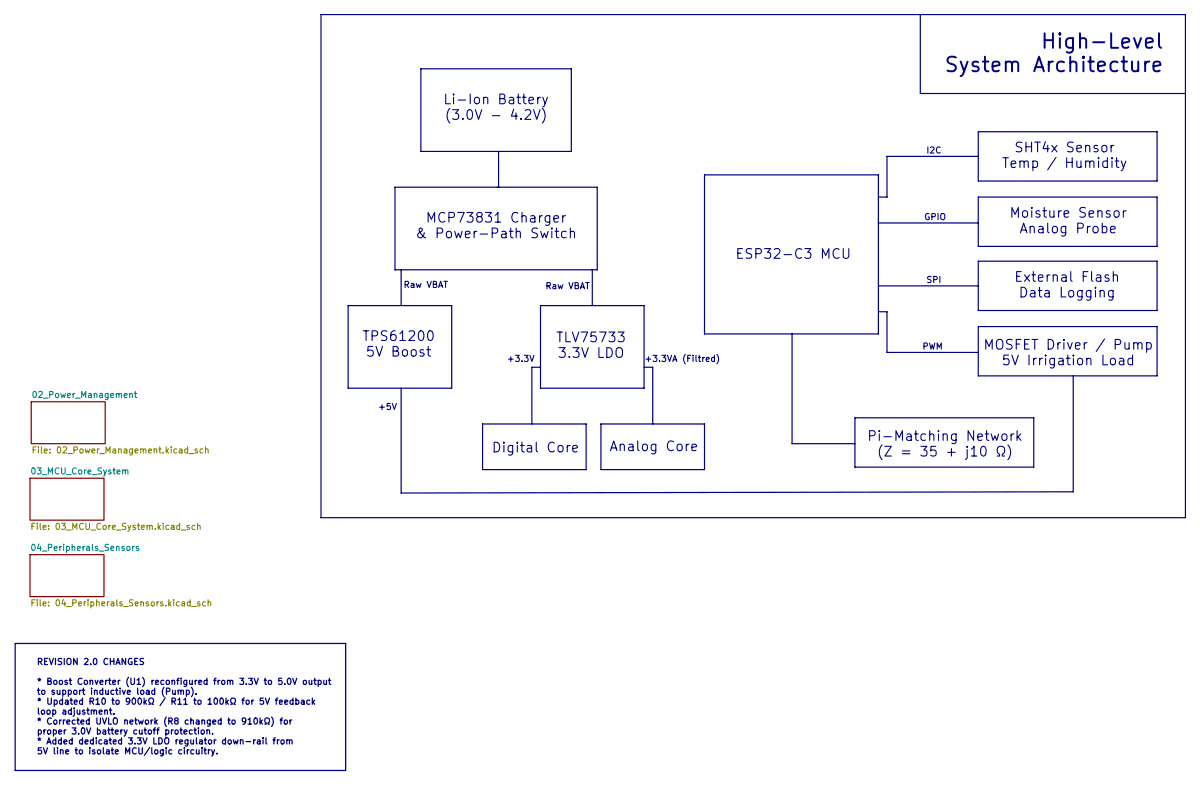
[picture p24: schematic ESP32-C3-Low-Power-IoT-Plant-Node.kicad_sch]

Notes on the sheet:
Moisture Sensor Analog Probe
Analog Core
ESP32-C3 MCU
Raw VBAT
+3.3VA (Filtred)
I2C
+5V
GPIO
Pi-Matching Network (Z = 35 + j10 Ω)
High-Level System Architecture
TLV75733 3.3V LDO
SPI
Digital Core
TPS61200 5V Boost
MOSFET Driver / Pump 5V Irrigation Load
REVISION 2.0 CHANGES * Boost Converter (U1) reconfigured from 3.3V to 5.0V output to support inductive load (Pump). * Updated R10 to 900kΩ / R11 to 100kΩ for 5V feedback loop adjustment. * Corrected UVLO network (R8 changed to 910kΩ) for proper 3.0V battery cutoff protection. * Added dedicated 3.3V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
SHT4x Sensor Temp / Humidity
PWM
MCP73831 Charger & Power-Path Switch
+3.3V
Li-Ion Battery (3.0V - 4.2V)
External Flash Data Logging

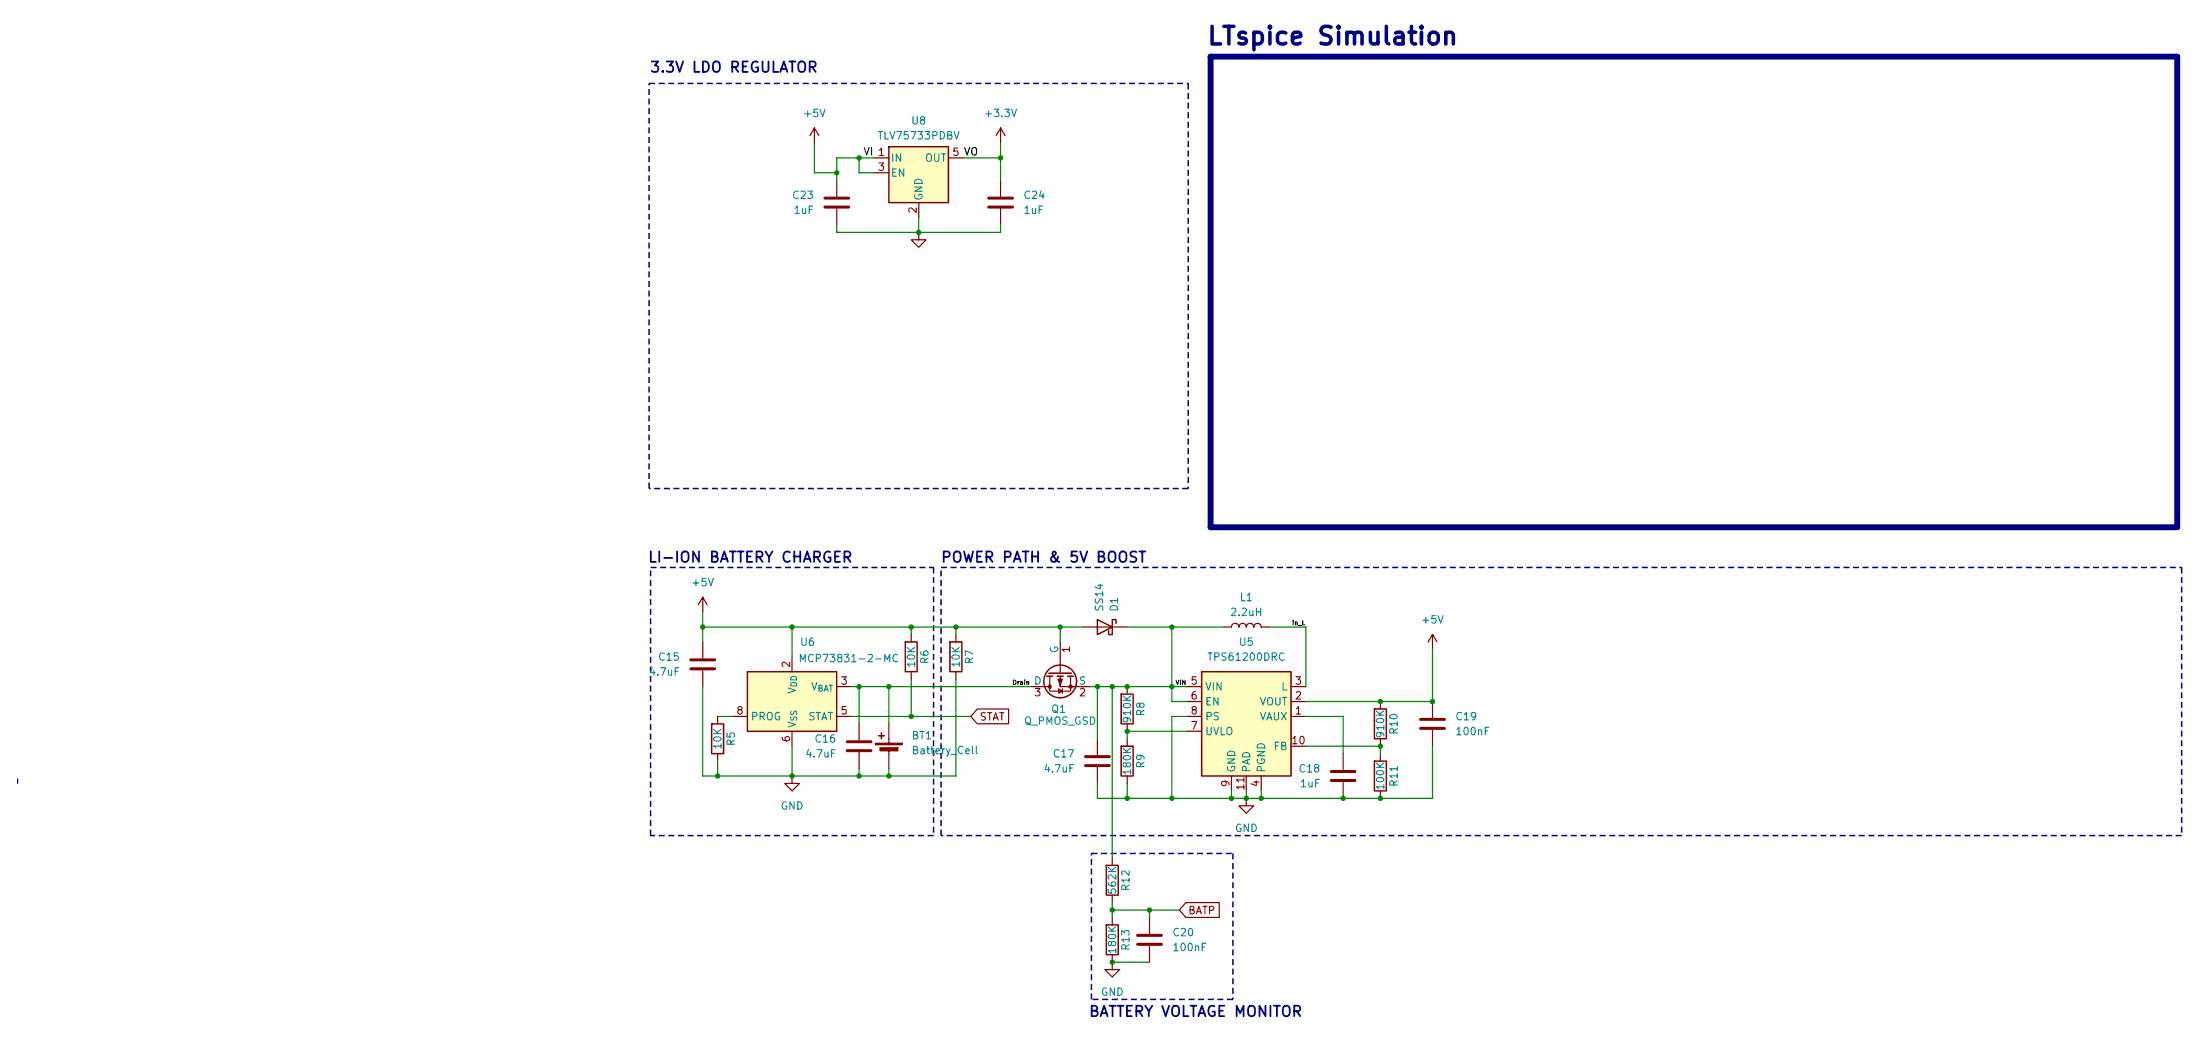
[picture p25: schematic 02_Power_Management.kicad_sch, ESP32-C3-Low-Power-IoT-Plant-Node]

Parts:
BT1: Battery_Cell; JST_PH_S2B-PH-K_1x02_P2.00mm_Horizontal
C15, C16, C17: 4.7uF; C_0402_1005Metric
C18, C23, C24: 1uF; C_0402_1005Metric
C19, C20: 100nF; C_0402_1005Metric
D1: SS14; D_SMA
L1: 2.2uH; R_0402_1005Metric
Q1: Q_PMOS_GSD; SOT-23
R5, R6, R7: 10K; R_0402_1005Metric
R8, R10: 910K; R_0402_1005Metric
R9, R13: 180K; R_0402_1005Metric
R11: 100K; R_0402_1005Metric
R12: 562K; R_0402_1005Metric
U5: TPS61200DRC; Texas_S-PVSON-N10_ThermalVias
U6: MCP73831-2-MC; DFN-8-1EP_3x2mm_P0.5mm_EP1.75x1.45mm
U8: TLV75733PDBV; SOT-23-5

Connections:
+3.3V: C24.1, U8.5 (OUT); also elsewhere on the board
+5V: C15.1, C19.1, C23.1, D1.2 (A), Q1.1 (G), R6.2, R7.2, R10.2, U5.2 (VOUT), U6.1 (V_{DD}), U6.2 (V_{DD}), U8.1 (IN), U8.3 (EN); also elsewhere on the board
/02_Power_Management/Drain: BT1.1 (+), C16.1, Q1.3 (D), U6.3 (V_{BAT}), U6.4 (V_{BAT})
/02_Power_Management/VIN: C17.1, D1.1 (K), L1.1, Q1.2 (S), R8.2, R12.2, U5.5 (VIN), U5.6 (EN)
/02_Power_Management/in_L: L1.2, U5.3 (L)
BATP: C20.1, R12.1, R13.2; also elsewhere on the board
GND: BT1.2 (-), C15.2, C16.2, C17.2, C18.2, C19.2, C20.2, C23.2, C24.2, R5.1, R7.1, R9.1, R11.1, R13.1, U5.4 (PGND), U5.8 (PS), U5.9 (GND), U5.11 (PAD), U6.6 (V_{SS}), U8.2 (GND); also elsewhere on the board
unnamed: R10.1, R11.2, U5.10 (FB)
unnamed: R8.1, R9.2, U5.7 (UVLO)
unnamed: C18.1, U5.1 (VAUX)
unnamed: R5.2, U6.8 (PROG)
STAT: R6.1, U6.5 (STAT); also elsewhere on the board

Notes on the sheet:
BATTERY VOLTAGE MONITOR
POWER PATH & 5V BOOST
3.3V LDO REGULATOR
LTspice Simulation
LI-ION BATTERY CHARGER

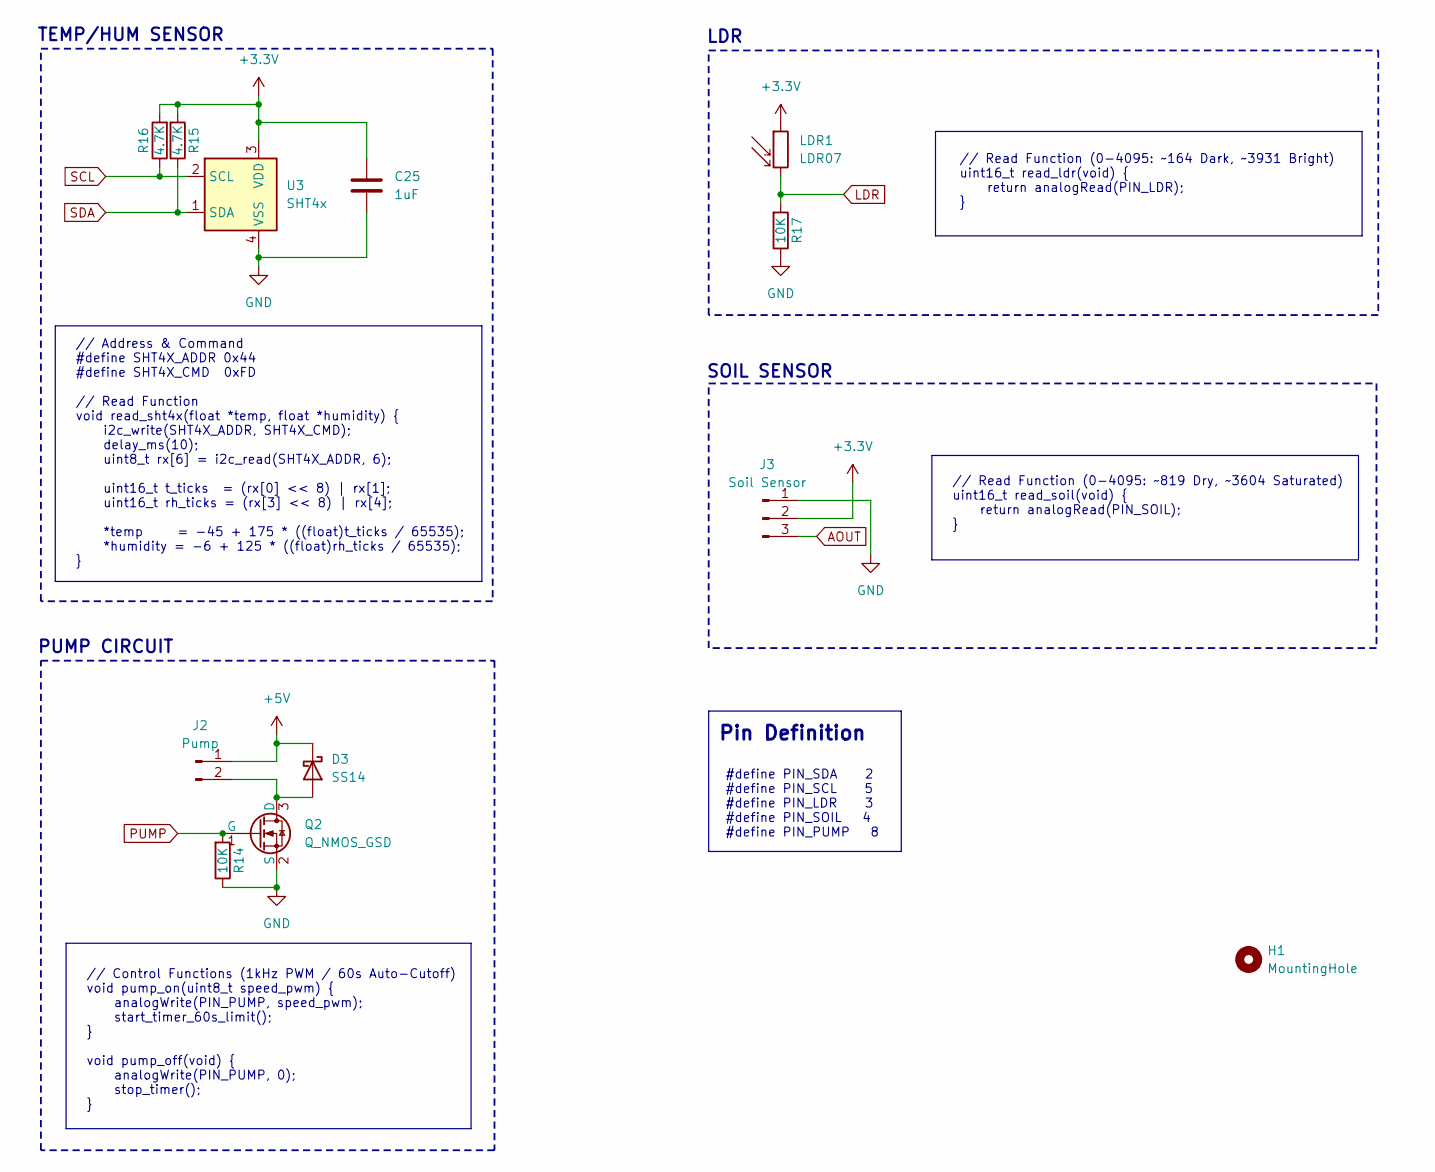
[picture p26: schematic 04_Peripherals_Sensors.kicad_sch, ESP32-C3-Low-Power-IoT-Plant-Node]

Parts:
C25: 1uF; C_0402_1005Metric
D3: SS14; D_SMA
H1: MountingHole; MountingHole_2.1mm
J2: Pump; JST_PH_B2B-PH-K_1x02_P2.00mm_Vertical
J3: Soil Sensor; JST_PH_B3B-PH-K_1x03_P2.00mm_Vertical
LDR1: LDR07; R_LDR_5.1x4.3mm_P3.4mm_Vertical
Q2: Q_NMOS_GSD; SOT-23
R14, R17: 10K; R_0402_1005Metric
R15, R16: 4.7K; R_0402_1005Metric
U3: SHT4x; Sensirion_DFN-4_1.5x1.5mm_P0.8mm_SHT4x_NoCentralPad

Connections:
+3.3V: C25.1, J3.2, LDR1.1, R15.2, R16.2, U3.3 (VDD); also elsewhere on the board
+5V: D3.1 (K), J2.1; also elsewhere on the board
AOUT: J3.3; also elsewhere on the board
GND: C25.2, J3.1, Q2.2 (S), R14.1, R17.1, U3.4 (VSS); also elsewhere on the board
LDR: LDR1.2, R17.2; also elsewhere on the board
unnamed: D3.2 (A), J2.2, Q2.3 (D)
PUMP: Q2.1 (G), R14.2; also elsewhere on the board
SCL: R16.1, U3.2 (SCL); also elsewhere on the board
SDA: R15.1, U3.1 (SDA); also elsewhere on the board

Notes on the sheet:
// Read Function (0-4095: ~164 Dark, ~3931 Bright) uint16_t read_ldr(void) { return analogRead(PIN_LDR); }
// Address & Command #define SHT4X_ADDR 0x44 #define SHT4X_CMD 0xFD // Read Function void read_sht4x(float *temp, float *humidity) { i2c_write(SHT4X_ADDR, SHT4X_CMD); delay_ms(10); uint8_t rx[6] = i2c_read(SHT4X_ADDR, 6); uint16_t t_ticks = (rx[0] << 8) | rx[1]; uint16_t rh_ticks = (rx[3] << 8) | r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
PUMP CIRCUIT
LDR
TEMP/HUM SENSOR
// Read Function (0-4095: ~819 Dry, ~3604 Saturated) uint16_t read_soil(void) { return analogRead(PIN_SOIL); }
// Control Functions (1kHz PWM / 60s Auto-Cutoff) void pump_on(uint8_t speed_pwm) { analogWrite(PIN_PUMP, speed_pwm); start_timer_60s_limit(); } void pump_off(void) { analogWrite(PIN_PUMP, 0); stop_timer(); }
#define PIN_SDA 2 #define PIN_SCL 5 #define PIN_LDR 3 #define PIN_SOIL 4 #define PIN_PUMP 8
Pin Definition
SOIL SENSOR

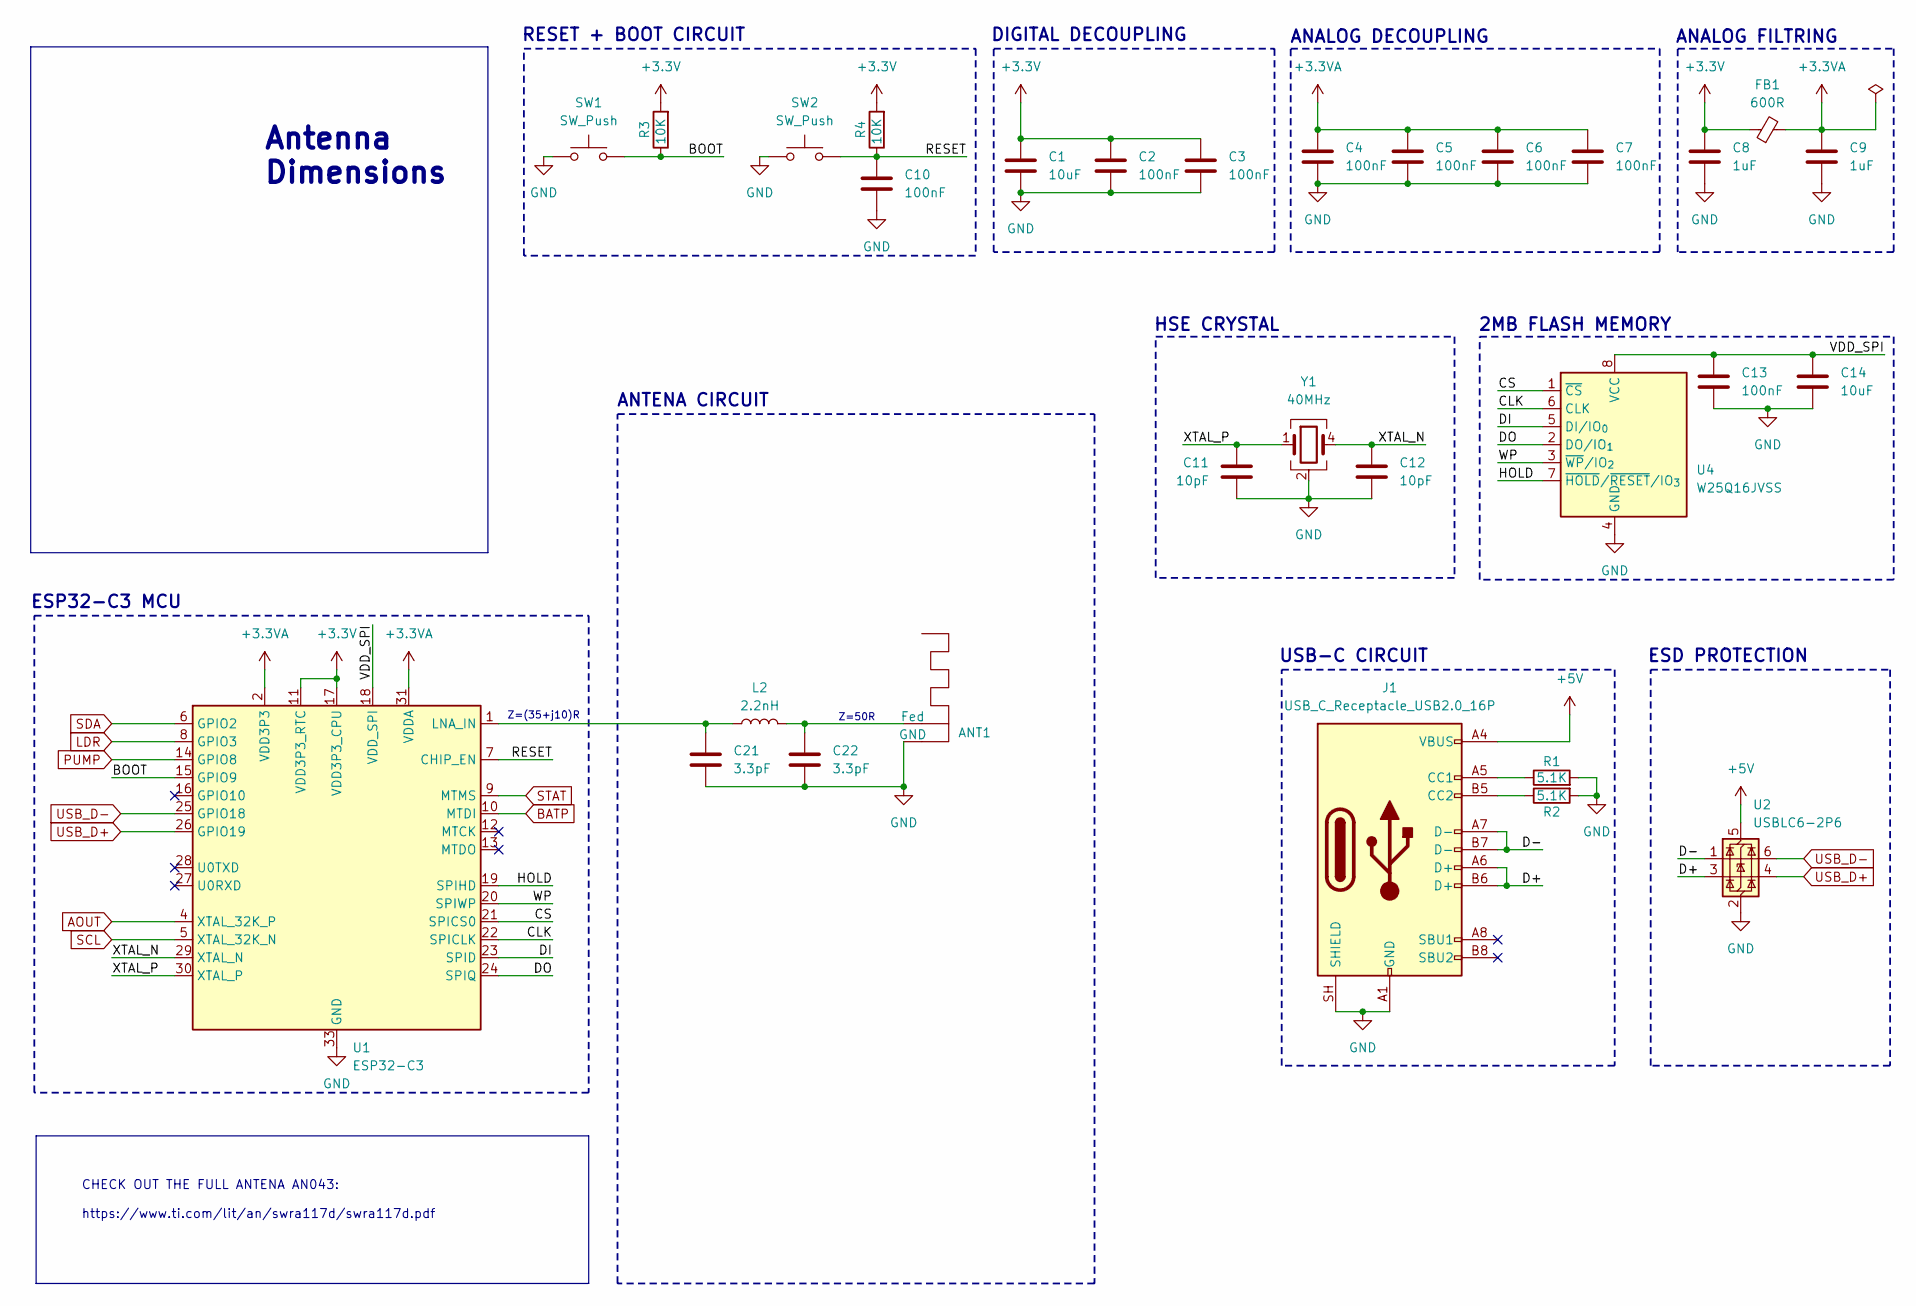
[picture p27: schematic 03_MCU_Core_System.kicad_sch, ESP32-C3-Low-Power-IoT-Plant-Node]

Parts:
ANT1: RF_TI_Antena_2.4GHz_flipped
C1, C14: 10uF; C_0402_1005Metric
C2, C3, C4, C5, C6, C7, C10, C13: 100nF; C_0402_1005Metric
C8, C9: 1uF; C_0402_1005Metric
C11, C12: 10pF; C_0402_1005Metric
C21, C22: 3.3pF; C_0402_1005Metric
FB1: 600R; R_0402_1005Metric
J1: USB_C_Receptacle_USB2.0_16P; USB_C_Receptacle_GCT_USB4105-xx-A_16P_TopMnt_Horizontal
L2: 2.2nH; R_0402_1005Metric
R1, R2: 5.1K; R_0402_1005Metric
R3, R4: 10K; R_0402_1005Metric
SW1, SW2: SW_Push; SW_Push_SPST_NO_Alps_SKRK
U1: ESP32-C3; QFN-32-1EP_5x5mm_P0.5mm_EP3.7x3.7mm
U2: USBLC6-2P6; SOT-666
U4: W25Q16JVSS; SOIC-8_5.3x5.3mm_P1.27mm
Y1: 40MHz; Crystal_SMD_3225-4Pin_3.2x2.5mm

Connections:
+3.3V: C1.1, C2.1, C3.1, C8.1, FB1.1, R3.2, R4.2, U1.11 (VDD3P3_RTC), U1.17 (VDD3P3_CPU); also elsewhere on the board
+3.3VA: C4.1, C5.1, C6.1, C7.1, C9.1, FB1.2, U1.2 (VDD3P3), U1.3 (VDD3P3), U1.31 (VDDA), U1.32 (VDDA)
+5V: J1.A4 (VBUS), J1.A9 (VBUS), J1.B4 (VBUS), J1.B9 (VBUS), U2.5 (VBUS); also elsewhere on the board
/03_MCU_Core_System/BOOT: R3.1, SW1.2, U1.15 (GPIO9)
/03_MCU_Core_System/CLK: U1.22 (SPICLK), U4.6 (CLK)
/03_MCU_Core_System/CS: U1.21 (SPICS0), U4.1 (~CS)
/03_MCU_Core_System/D+: J1.A6 (D+), J1.B6 (D+), U2.3 (I/O2)
/03_MCU_Core_System/D-: J1.A7 (D-), J1.B7 (D-), U2.1 (I/O1)
/03_MCU_Core_System/DI: U1.23 (SPID), U4.5 (DI/IO_{0})
/03_MCU_Core_System/DO: U1.24 (SPIQ), U4.2 (DO/IO_{1})
/03_MCU_Core_System/HOLD: U1.19 (SPIHD), U4.7 (~HOLD/~RESET/IO_{3})
/03_MCU_Core_System/RESET: C10.1, R4.1, SW2.2, U1.7 (CHIP_EN)
/03_MCU_Core_System/VDD_SPI: C13.1, C14.1, U1.18 (VDD_SPI), U4.8 (VCC)
/03_MCU_Core_System/WP: U1.20 (SPIWP), U4.3 (~WP/IO_{2})
/03_MCU_Core_System/XTAL_N: C12.1, U1.29 (XTAL_N), Y1.4
/03_MCU_Core_System/XTAL_P: C11.1, U1.30 (XTAL_P), Y1.1
AOUT: U1.4 (XTAL_32K_P); also elsewhere on the board
BATP: U1.10 (MTDI); also elsewhere on the board
GND: ANT1.2 (GND), C1.2, C2.2, C3.2, C4.2, C5.2, C6.2, C7.2, C8.2, C9.2, C10.2, C11.2, C12.2, C13.2, C14.2, C21.2, C22.2, J1.A1 (GND), J1.A12 (GND), J1.B1 (GND), J1.B12 (GND), J1.SH (SHIELD), R1.2, R2.2, SW1.1, SW2.1, U1.33 (GND), U2.2 (GND), U4.4 (GND), Y1.2 (G), Y1.3 (G); also elsewhere on the board
LDR: U1.8 (GPIO3); also elsewhere on the board
unnamed: ANT1.1 (Fed), C22.1, L2.2
unnamed: J1.A5 (CC1), R1.1
unnamed: J1.B5 (CC2), R2.1
unnamed: C21.1, L2.1, U1.1 (LNA_IN)
PUMP: U1.14 (GPIO8); also elsewhere on the board
SCL: U1.5 (XTAL_32K_N); also elsewhere on the board
SDA: U1.6 (GPIO2); also elsewhere on the board
STAT: U1.9 (MTMS); also elsewhere on the board
USB_D+: U1.26 (GPIO19), U2.4 (I/O2)
USB_D-: U1.25 (GPIO18), U2.6 (I/O1)

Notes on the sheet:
ANALOG FILTRING
ESD PROTECTION
2MB FLASH MEMORY
CHECK OUT THE FULL ANTENA AN043: https://www.ti.com/lit/an/swra117d/swra117d.pdf
HSE CRYSTAL
USB-C CIRCUIT
Z=(35+j10)R
ANALOG DECOUPLING
Antenna Dimensions
RESET + BOOT CIRCUIT
ANTENA CIRCUIT
Z=50R
ESP32-C3 MCU
DIGITAL DECOUPLING

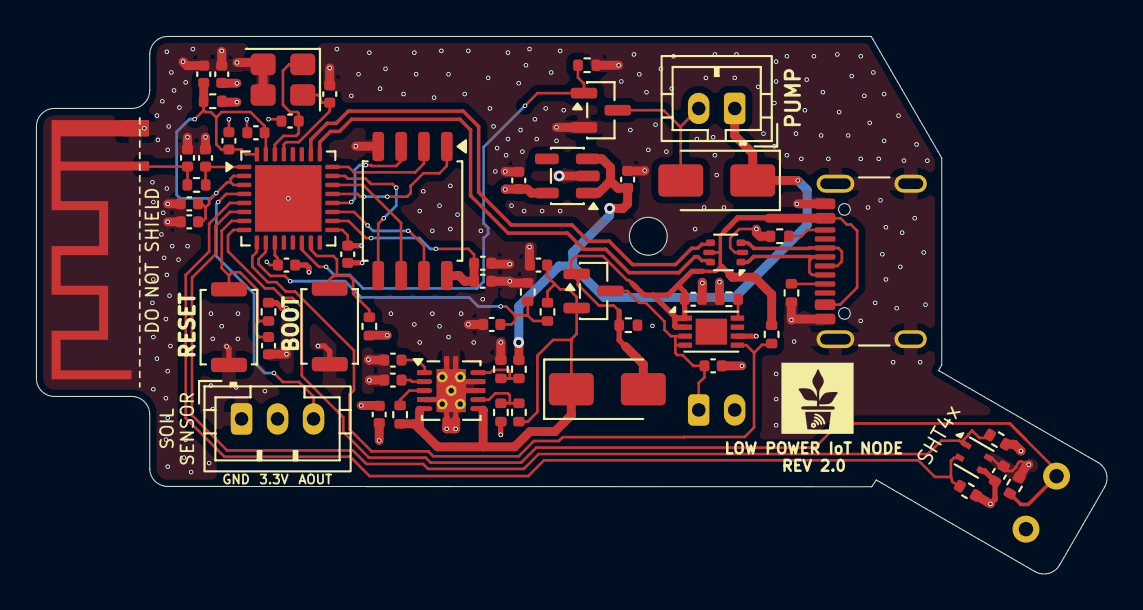
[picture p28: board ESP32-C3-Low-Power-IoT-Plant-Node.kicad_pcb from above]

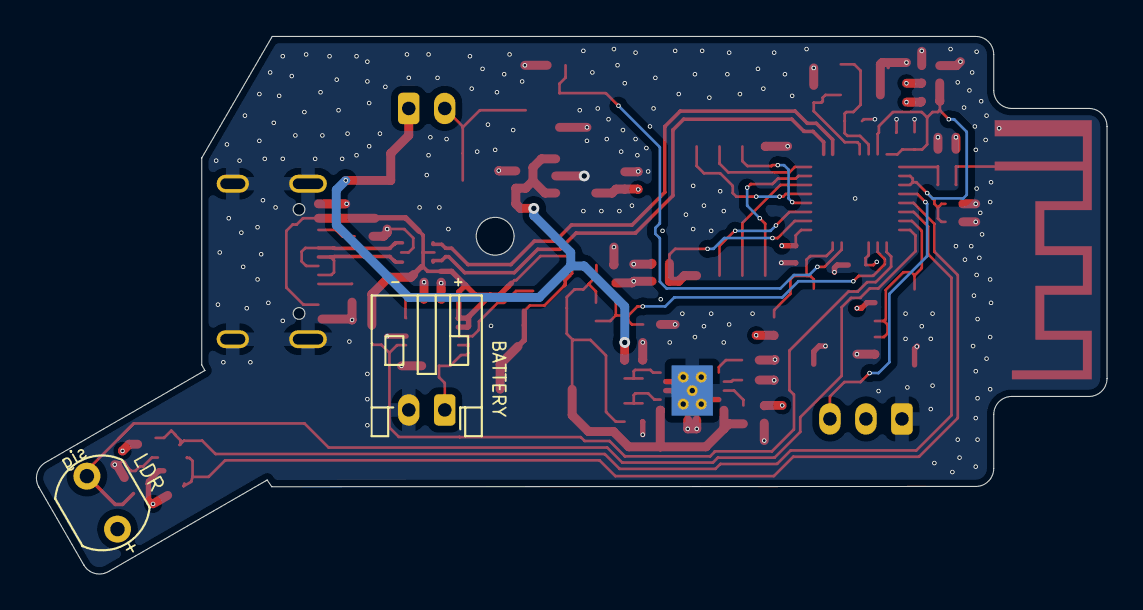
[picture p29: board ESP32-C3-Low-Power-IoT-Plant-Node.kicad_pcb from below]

Board: 4 copper layers, 59.5 x 29.9 mm, 66 parts (2 on the bottom side), 38 nets.

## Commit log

2026-07-27 Initial release
    [.step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]
2026-09-07 Update hardware design to Rev 2.0
    [02_Power_Management.kicad_sch, 03_MCU_Core_System.kicad_sch, 04_Peripherals_Sensors.kicad_sch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]
